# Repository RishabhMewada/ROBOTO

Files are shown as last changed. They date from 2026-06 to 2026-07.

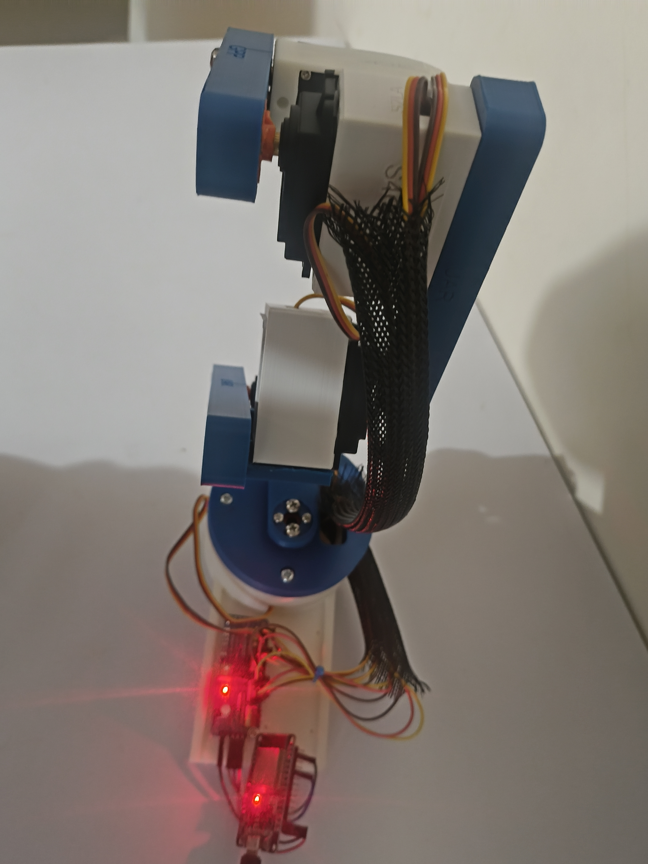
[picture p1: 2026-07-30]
Photos/IMG_20260730_174943996.jpg

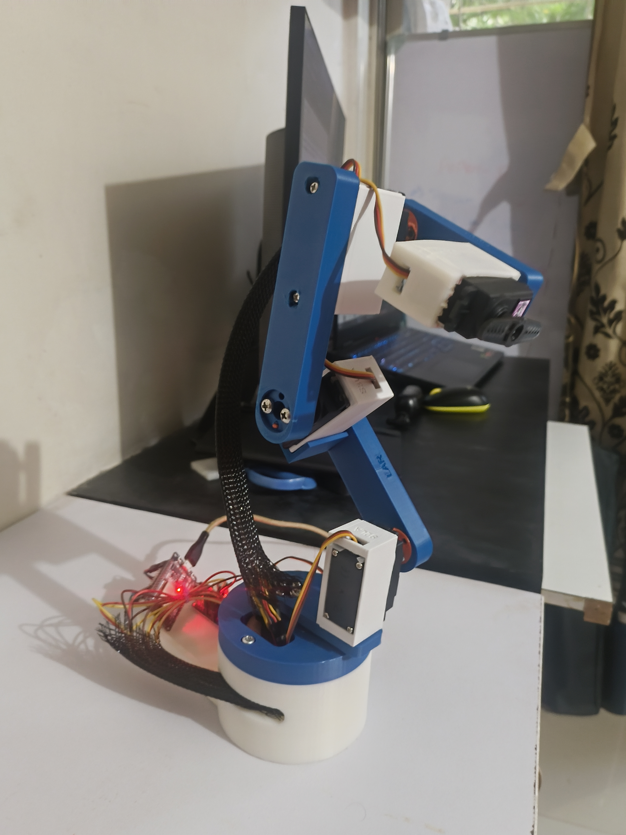
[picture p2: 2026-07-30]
Photos/IMG_20260730_175032654.jpg

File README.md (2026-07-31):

# ROBOTO

RB-1 (2)

>  An 6 degree of freedom (dof) robot driven by Waveshare WP5320 servo and an esp32 and
  servo driver the robot is controlled from a glove consisting of an esp32 & BNO055 and a
  battery pack

demo


## Table of Contents
- [Overview](#overview)
- [Hardware](#Hardware-&-Wiring-Diagram)
- [Software Architecture](#software-architecture)

## Overview
>'The why?'
 
**The sole purpose of this project is to help people build stuff and make them learn about robotics in comparatively affordable price and tinker around, in a much easier way to build and learn** and to be honest i also wanted to learn about robotics and improve my skills and build stuff which is hard to build !!

>The what?

**The project was build with one thing in mind, make it easy to connect and build (Like lego's !) , the project works on an ESP32 , and a PCA9685 servo driver to control the servo's and the servos's which are used in this project is Waveshare WP5320 *(it's MG996R servo in the project as it has similar diemensions to the WP5320 as i was not able to find the STEP file for it)* and BNO055 IMU to control the robot via hand gestures and a battery pack to power the glove side**

> The how?

**The project was Inspired from the S101 robot Repository and is built in fusion 360 with a minimilist Design Philosophy with a yet strong  build enough to handle its own weight and the objects it picks up without any bottleneck between the servo and it's built quality , and the entire robotic arm is build from ABS 3D printing material for a strong build with also some PLA in some parts of the robotic arm**

<p align="center">
ROBOTO-PARTS_2026-May-29_05-07-04PM-000_CustomizedView9396335264
</p>

## Hardware & Wiring Diagram

**Use the Wiring diagram as the Pin map for connecting everything and use the link above the diagram to get the exact pins!**

>Hardware (Robotic Arm)

1. ESP32 
2. PCA9685 Servo driver
3. Waveshare WP5320 Servo 180 Degree

>Wiring Schematic (Robotic Arm)

 [Click here to view the Schematic!](https://app.cirkitdesigner.com/project/19c6ec55-5556-4408-a9a6-c3da8fffa251)
 
RB-1 (3)

----------------------------------------------------------------------------------------------------------------------------------------------------------------------------------------------------------------------

>*Hardware (Glove)*

-Battery pack
1. 18650 Battery
2. TP4056 battery charger
3. MT608 boost converter
4. rocker switch
  
-Motion capture module
1. ESP32
2. BNO055 IMU 9-DOF
3. Flex Sensor
   
>Wiring Schematic (Glove)

 [Click here to view the Schematic!](https://app.cirkitdesigner.com/project/269f68dc-bc2f-4ff6-8df4-b6a70eb212e9)

RB-1

-----------------------------------------------------------------------------------------------------------------------------------------------------------------------------------------------------------------------------

### Bill of Materials

> Total project cost: **~$173.31 USD**

## Electronics

| # | Component | Purpose | Qty | Cost (USD) | Distributor |
|---|---|---|:---:|:---:|---|
| 1 | [ESP32 WROOM-32](https://robu.in/product/esp-wroom-32-wifi-bluetooth-networking-smart-component-development-board/) | Main control unit (glove + arm) | 2 | $8.70 | Robu.in |
| 2 | [BNO055 IMU](https://robu.in/product/df-robot-febno055-intelligent-9-axis-sensor-rmion-bno055-intelligent-9-axis-sensor-breakout/) | 9-axis IMU for arm motion tracking | 1 | $19.87 | Robu.in |
| 3 | [PCA9685](https://robocraze.com/products/pca9685-16-channel-servo-motor-driversoldered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) | 16-channel 12-bit servo driver | 1 | $2.40 | Robocraze.com |
| 4 | [WP5320 Servo](https://hubtronics.in/wp5320) | Arm joints + gripper (×6) | 6 | $82.30 | Hubtronics.in |
| 5 | [Flex Sensor 2.2"](https://robocraze.com/products/flex-sensor-2-2?variant=40192405504153&country=IN&currency=INR) | Gripper trigger on glove | 1 | $2.03 | Robocraze.com |

## Power System

| # | Component | Purpose | Qty | Cost (USD) | Distributor |
|---|---|---|:---:|:---:|---|
| 6 | [Samsung 18650 Li-Ion Battery](https://robu.in/product/samsung-18650-30q-li-ion-battery/) | Main power source for glove | 1 | $6.06 | Robu.in |
| 7 | [18650 Battery Holder](https://robu.in/product/1-x-18650-cell-box/) | Battery housing | 1 | $6.06 | Robu.in |
| 8 | [TP4056 Charger Module](https://robocraze.com/products/tp4056-battery-charger-c-type-module-with-protection-1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) | Li-Ion battery charger with protection | 1 | $0.15 | Robocraze.com |
| 9 | [MT3608 Boost Converter](https://robu.in/product/mt3608-2a-max-dc-dc-step-up-power-module-booster-power-module/) | Steps up battery voltage for ESP32 | 1 | $0.35 | Robocraze.com |
| 10 | [Rocker Switch](https://robu.in/product/6a-250v-ac-spst-on-off-rocker-switch/) | Power on/off | 1 | $0.17 | Robu.in |

## Mechanical & Build

| # | Component | Purpose | Qty | Cost (USD) | Distributor |
|---|---|---|:---:|:---:|---|
| 11 | [3D Printing Service](https://robu.in/product/3d-printing-service1/) | Arm structure parts | 16 | $34.96 | Robu.in |
| 12 | [Screws & Thread Inserts](https://onlyscrews.in/a/cart?cart-token=2tY5s2&link-token=10JKFq) | Assembly hardware | 1 | $4.10 | onlyscrews.in |

## Glove Assembly

| # | Component | Purpose | Qty | Cost (USD) | Distributor |
|---|---|---|:---:|:---:|---|
| 13 | [Fingerless Compression Glove](https://www.amazon.in/MOMISY-Copper-Infused-Fingerless-Compression-Tendonitis/dp/B09HV4BFLP) | Base for motion sensor pack | 1 | $5.02 | Amazon.in |
| 14 | [Velcro Straps](https://www.amazon.in/Glimzo-Velcro-Tape-Buckles-Management/dp/B0GX9J13YC) | Holds battery pack on hand | 1 | $0.72 | Amazon.in |
| 15 | [Jumper Wires (F-F 10cm)](https://robu.in/product/10cm-female-female-breadboard-jumper-dupont-2-54mm-1p-1p-cable-40-pcs/) | Module connections | 1 | $0.42 | Robu.in |

---

> **Note:** Prices are in USD and may vary by region. All Indian suppliers ship domestically.
> Servo power supply (5–6 V / 3 A BEC) is required separately for the arm and is not included above. 

## Software Architecture

- The system is split across two independent ESP32 microcontrollers communicating wirelessly in real time. The glove controller reads motion and finger data and then packages it into a compact struct, and broadcasts it over to the ESP-NOW at 50 Hz.
  
- The arm controller receives each packet and maps the orientation values to servo angles and it applies exponential smoothing, and drives six WP5320 servos through a PCA9685 PWM driver. No router, no Bluetooth pairing, no internet — the two boards talk directly peer-to-peer over 2.4 GHz with sub-5 ms latency
-----------------------------------------------------------------------------------------------------------------------------------------------------------------------------------------------------------------
## System Diagram

<p align="center">
 Group 1
</p>

-----------------------------------------------------------------------------------------------------------------------------------------------------------------------------------------------------------------

## Folder Structure

```robotic-glove-arm/
│
├── firmware/
│   ├── arm_esp32/
│   │   └── arm_esp32.ino        # Arm controller — ESP-NOW RX, PCA9685, servo mapping
│   ├── glove_esp32/
│   │   └── glove_esp32.ino      # Glove controller — BNO055, flex sensor, ESP-NOW TX
│   └── shared/
│       └── config.h             # GlovePacket struct, pin defines, shared constants
│
├── hardware/
│   ├── schematics/
│   │   ├── glove_wiring.png     # Exported wiring diagram
│   │   └── arm_wiring.png       # Exported wiring diagram
│   ├── cad/
│   │   └── arm_assembly.step    # Full CAD assembly of the robot
|   |   └── 3D print Files       #  3D models for 3D printing
│   └── BOM.csv                  # Part, qty, supplier, price, link
│
├── Images/
│   ├── banner.png               # README header image (1500×500 px)
|   └── robtic arm & glove       # CAD images of the robot and the glove
│
├── README.md
├── CHANGELOG.md
├── LICENSE
└── .gitignore
```

## Communication Protocol

- The two boards communicate exclusively over ESP-NOW — a connectionless, peer-to-peer Wi-Fi protocol built into the ESP32. No pairing process, no router required, and no TCP overhead. Once the arm's MAC address is registered as a peer on the glove, packets fire unidirectionally from glove to arm at 50 Hz with approximately 2–4 ms over-the-air latency.
Packet structure — GlovePacket (30 bytes)

```typedef struct __attribute__((packed)) {
    float    roll;        // degrees, offset-corrected  (-180 … +180)
    float    pitch;       // degrees, offset-corrected  (-90  … +90)
    float    yaw;         // degrees, offset-corrected  (0    … 360)
    float    quatW;       // quaternion W component
    float    quatX;       // quaternion X component
    float    quatY;       // quaternion Y component
    float    quatZ;       // quaternion Z component
    uint8_t  gripClose;   // 1 = close gripper, 0 = open
    uint8_t  calMode;     // 1 = calibration reset signal, 0 = normal
    int16_t  flexRaw;     // raw ADC value (0–4095) for diagnostics
} GlovePacket;            // total: 30 bytes
```
- Transmission
  
| Property | Value |
|---|---|
| Protocol | ESP-NOW (IEEE 802.11 vendor action frames) |
| Direction | Glove → Arm (unidirectional) |
| Frequency | 50 Hz (every 20 ms) |
| Packet size | 30 bytes |
| Latency | ~2–4 ms |
| Range | ~200 m open air, ~50 m indoors |
| Encryption | None (add `encrypt: true` in peer config to enable) |
| Timeout | 500 ms — arm returns to HOME if no packet received |

- Calibration packets — 

**when the user triggers calibration on the glove (BOOT button held 3 s), the glove captures its neutral orientation and flex thresholds, saves them to NVS, then sends one packet with calMode = 1. The arm receives this and moves to HOME position, resetting its own smoothing state. Normal calMode = 0 packets resume immediately after**

- Connection loss handling — 

**the arm tracks the timestamp of the last received packet. If 500 ms passes with no packet (glove powered off, out of range, or obstruction), all servo targets are set to HOME and the status LED blinks at 300 ms intervals until signal resumes**

------------------------------------------------------------------------------------------------------------------------------------------------------------------------------------------------------------------------
## Build it !!

### firmware

***for the step by step guide on how to install the firmware on the ESP32 and download the  Prerequisites required for the installation of the firmware on ESP32 and make it work please go to the guide pdf***
it would be lenghty to write it here
                                                                                 
```
Firmware-installation.pdf

``` 

## Wirring steps 

please follow the schematic diagram in the readme or visit the links here, and connect everything via female to female jumper wires or solder them wires onto the components , i recommend jumper wires it keeps the project components resuable!

1. [Click here to view the Schematic!](https://app.cirkitdesigner.com/project/19c6ec55-5556-4408-a9a6-c3da8fffa251) for the wiring of the robotic arm

2.  [Click here to view the Schematic!](https://app.cirkitdesigner.com/project/269f68dc-bc2f-4ff6-8df4-b6a70eb212e9) for the wiring of glove

please note that the wiring in glove will require the components to be soldered via wires, which should be connected by following the schematics for both the glove and the Arm

## Robotic Arm build & glove build

 **Robotic Arm build**
please refer to this video made from hack club lapse , this will help you make the robotic arm easily by viewing it properly and following the steps , currently its in video form after full completion there would be a dedicated guide pdf for everything as a go to solution

*Video Links*

Base : https://lapse.hackclub.com/timelapse/fq3q5Q8XxO8g

Arm : https://lapse.hackclub.com/timelapse/Uputkgdq-GtG

**alternatively there is also the video in  repository file**

```
 Video-guide/

```

**there are also photos in the** 

```
Photos/

```
**for your reference !**
 
## Usage & Demo
 Let me complete the build first !
 
## License
**MIT LICENSE**

## Zine
 <p align="center">
 RB-1
</p>

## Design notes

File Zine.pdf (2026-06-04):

# Not a

# normal Robot

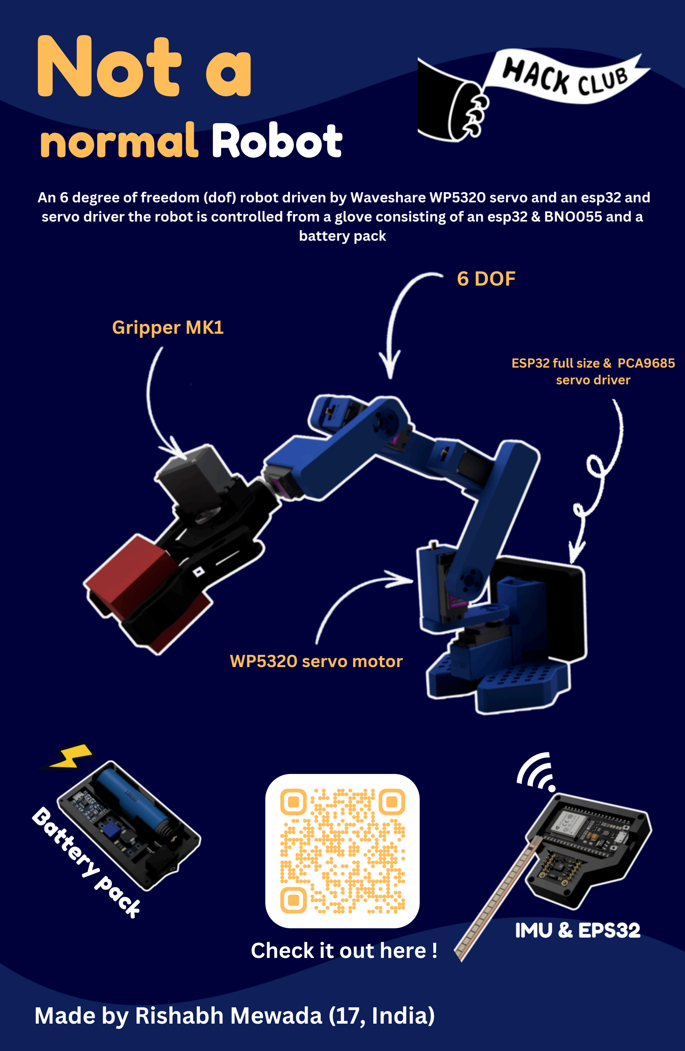
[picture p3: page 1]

An 6 degree of freedom (dof) robot driven by Waveshare WP5320 servo and an esp32 and servo driver the robot is controlled from a glove consisting of an esp32 & BNO055 and a battery pack

## Check it out here !

## Gripper MK1

## 6 DOF

### WP5320 servo motor

ESP32 full size & PCA9685
servo driver

# Battery pack

## IMU & EPS32

## Made by Rishabh Mewada (17, India)

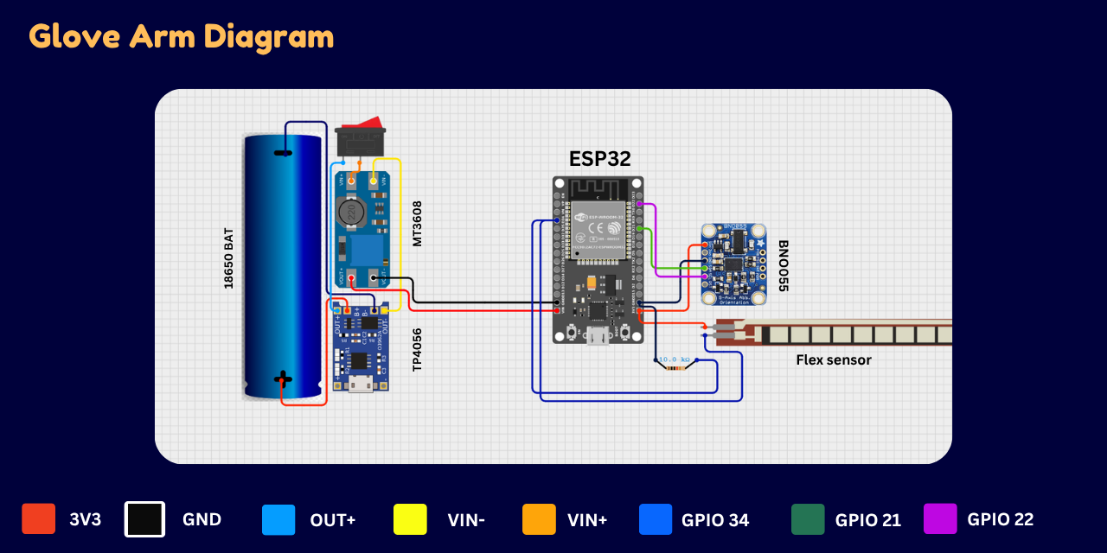
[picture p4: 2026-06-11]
Hardware/Schematics/Glove-Schematics.png

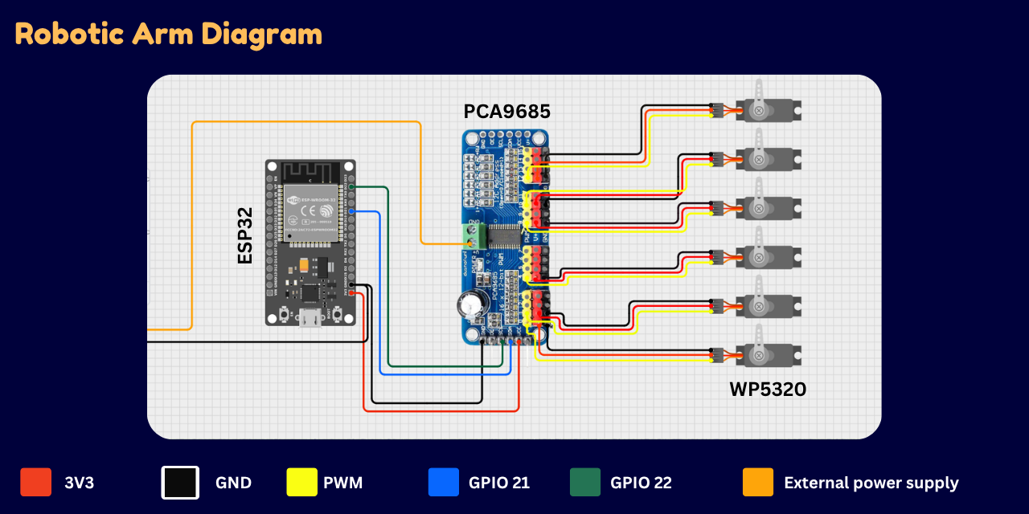
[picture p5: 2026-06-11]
Hardware/Schematics/RoboticArm-Schematics.png

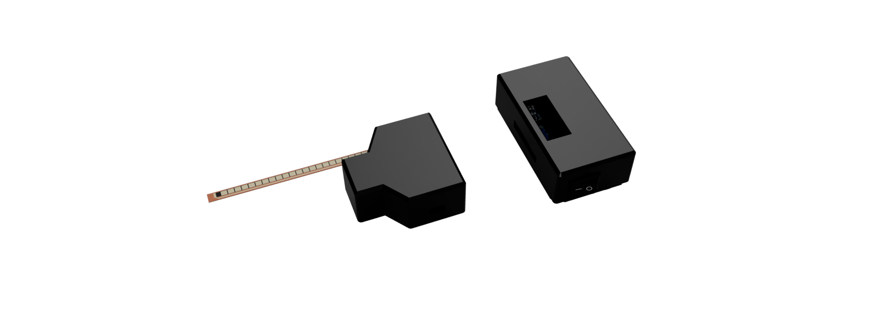
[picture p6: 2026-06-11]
Images/Glove-Images/glove-cad.PNG

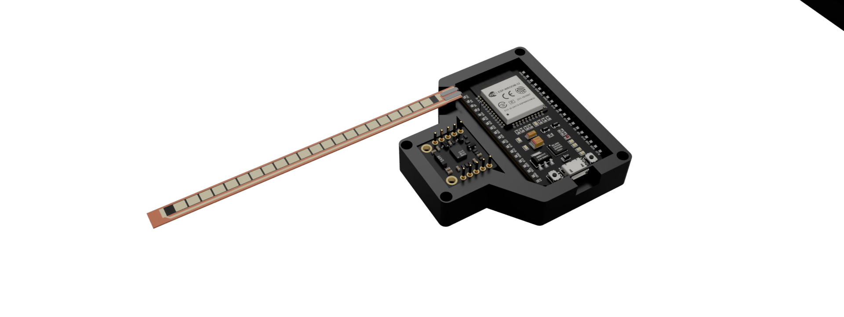
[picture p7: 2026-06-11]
Images/Glove-Images/ROBOTO-GLOVE-BNO055 & ESP32.png

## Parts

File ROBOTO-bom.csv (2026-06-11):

Name | Purpose | Quantity | Total Cost (USD) | Link | Distributor
screws and thread inserts | build | 1 | 4.10 | https://onlyscrews.in/a/cart?cart-token=2tY5s2&link-token=10JKFq | onlyscrews.in
3D Printing | build | 16 | 34.96 | https://robu.in/product/3d-printing-service1/ | Robu.in
Gloves | holding the motion sensor pack | 1 | 5.02 | https://www.amazon.in/MOMISY-Copper-Infused-Fingerless-Compression-Tendonitis/dp/B09HV4BFLP | Amazon.in
straps | for holding the battery pack on my hand | 1 | 0.72 | https://www.amazon.in/Glimzo-Velcro-Tape-Buckles-Management/dp/B0GX9J13YC | amazon.in
jumper wires | connection of modules | 1 | 0.42 | https://robu.in/product/10cm-female-female-breadboard-jumper-dupont-2-54mm-1p-1p-cable-40-pcs/ | Robu.in
flex sensor | gripper movement | 1 | 2.03 | https://robocraze.com/products/flex-sensor-2-2?variant=40192405504153&country=IN&currency=INR | Robocraze.com
BNO055 | IMU for robotic arm movement | 1 | 19.87 | https://robu.in/product/df-robot-febno055-intelligent-9-axis-sensor-rmion-bno055-intelligent-9-axis-sensor-breakout/ | Robu.in
switch | on/off | 1 | 0.17 | https://robu.in/product/6a-250v-ac-spst-on-off-rocker-switch/ | robu.in
MT3608 | Boost converter | 1 | 0.35 | https://robu.in/product/mt3608-2a-max-dc-dc-step-up-power-module-booster-power-module/ | robocraze.com
TP4056 | Battery charger | 1 | 0.15 | https://robocraze.com/products/tp4056-battery-charger-c-type-module-with-protection-1?variant=46170796261600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 | robocraze.com
18650 Battery holder | battery holder | 1 | 6.06 | https://robu.in/product/1-x-18650-cell-box/ | robu.in
18650 Li-Ion battery | battery | 1 | 6.06 | https://robu.in/product/samsung-18650-30q-li-ion-battery/ | robu.in
PCA9685 | Servo driver | 1 | 2.40 | https://robocraze.com/products/pca9685-16-channel-servo-motor-driversoldered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 | robocraze.com
WP5320 | SERVO | 6 | 82.30 | https://hubtronics.in/wp5320 | Hubtronics.in
ESP32 | Main control unit | 2 | 8.70 | https://robu.in/product/esp-wroom-32-wifi-bluetooth-networking-smart-component-development-board/ | Robu.in

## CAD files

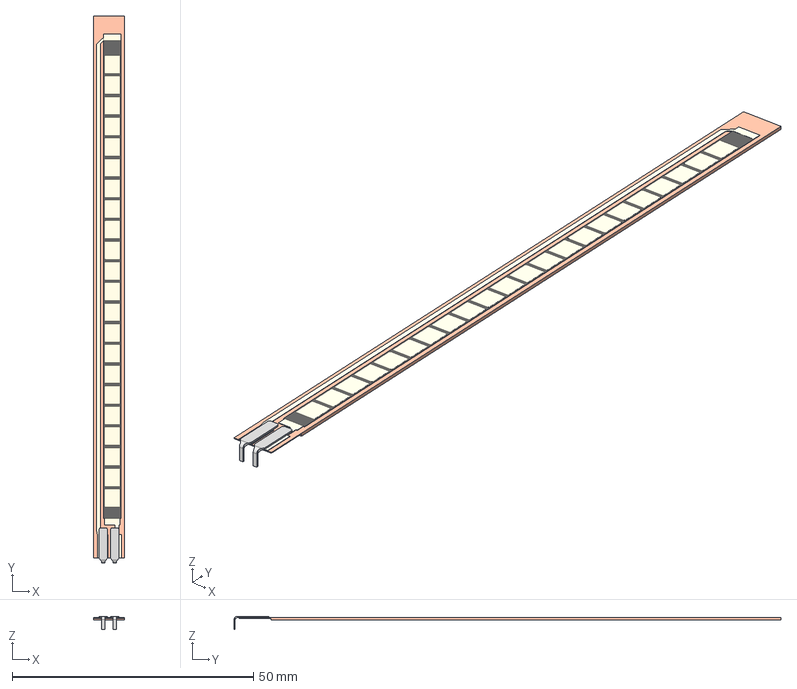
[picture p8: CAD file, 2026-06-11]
Component Library/FS-L-0095-103-ST - Assembly.stp
6.45 x 113.5 x 2.77 mm
FS-L-0095-103-ST - Base
FS-L-0095-103-ST - Top

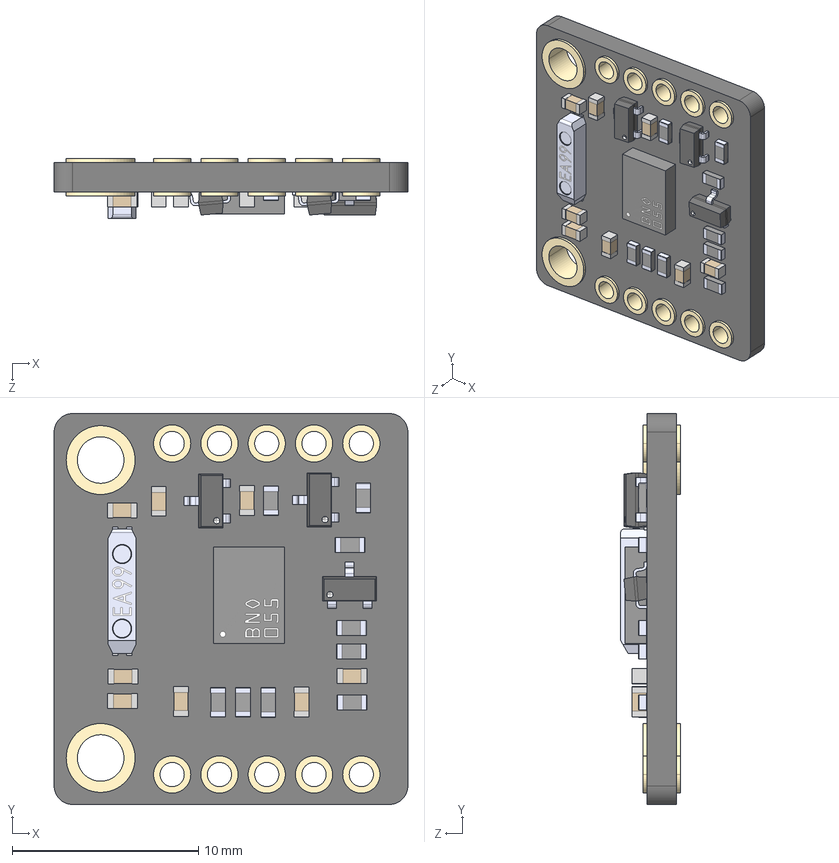
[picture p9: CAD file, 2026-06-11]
Component Library/bno055.STEP
19.0 x 21.0 x 3.20 mm
bno055_asm
User Library-LGA-28_5_2x3_8_0_5p.step
80836.stp x 9
User Library-SOT23-3.step x 3
capacitor_rnd_1500603b221k500.stp x 8
User Library-CSYTAL-MC146.step

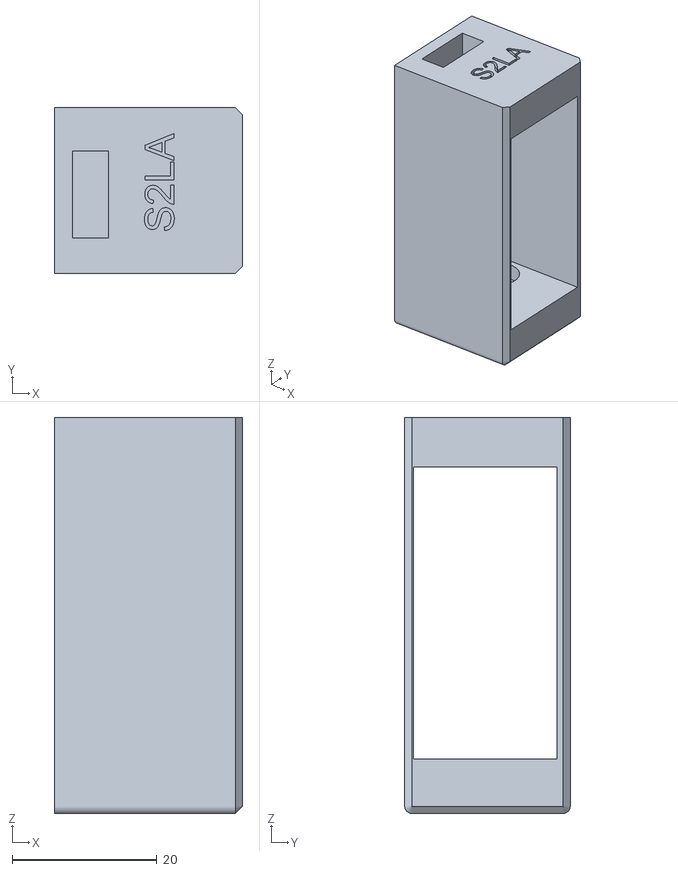
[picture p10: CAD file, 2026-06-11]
Hardware/3D Print/Arm-3D-Print/S2LA.stl
26.0 x 22.9 x 54.7

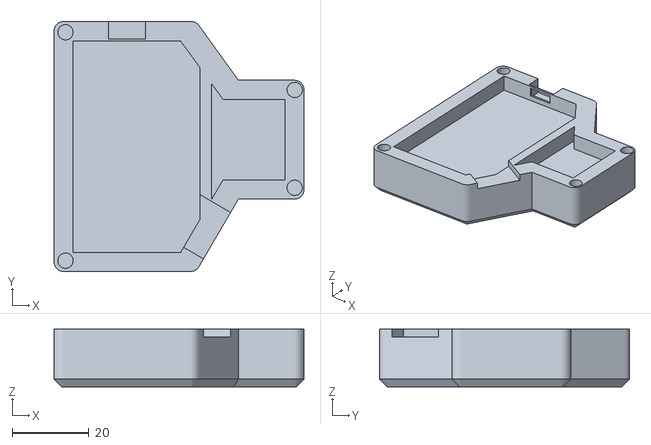
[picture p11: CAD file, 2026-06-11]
Hardware/3D Print/Glove-3D-print/GLOVE-SENSORBOX-LOWER.stl
65.1 x 65.1 x 15.0

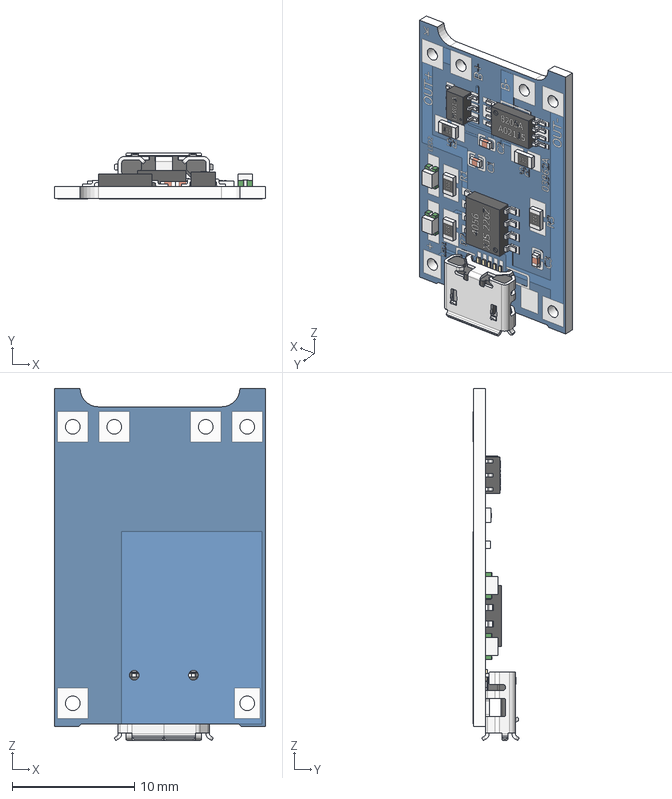
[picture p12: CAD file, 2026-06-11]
Component Library/TP4056.stp
17.3 x 3.75 x 28.9 mm
Board_TP4056
XJS_226Z
DW01-A
A02115
Capacitor_0603 x 3
Resistor (0603) x 3
Resistor (0603)_1
Resistor (0603)_2
Led x 2
Micro USB-B Female 5Pin SMD

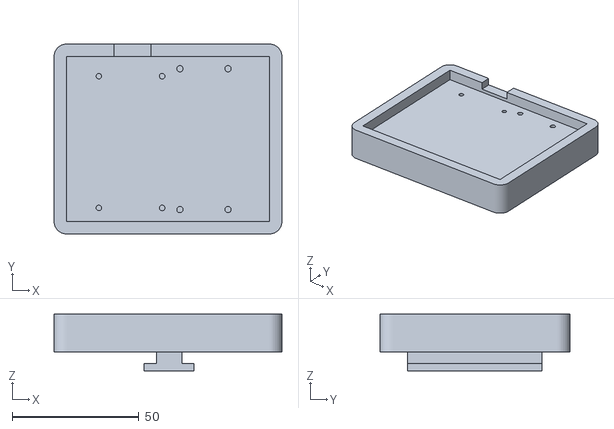
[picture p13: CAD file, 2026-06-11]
Hardware/3D Print/Arm-3D-Print/Mounting-plate.stl
90.0 x 75.0 x 22.4

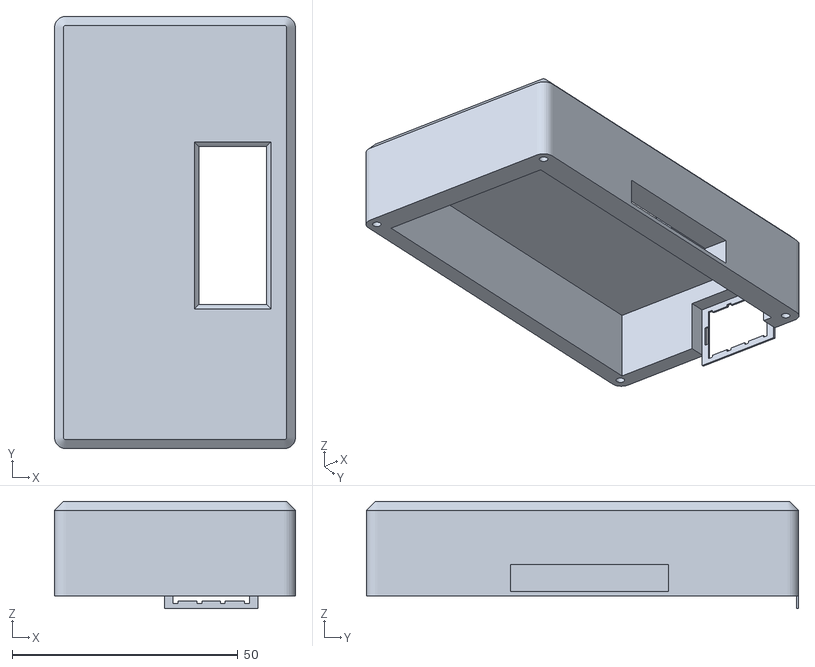
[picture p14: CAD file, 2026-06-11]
Hardware/3D Print/Glove-3D-print/GLOVE-BATTERYBOX-UPPERCASE.stl
53.4 x 95.9 x 23.8

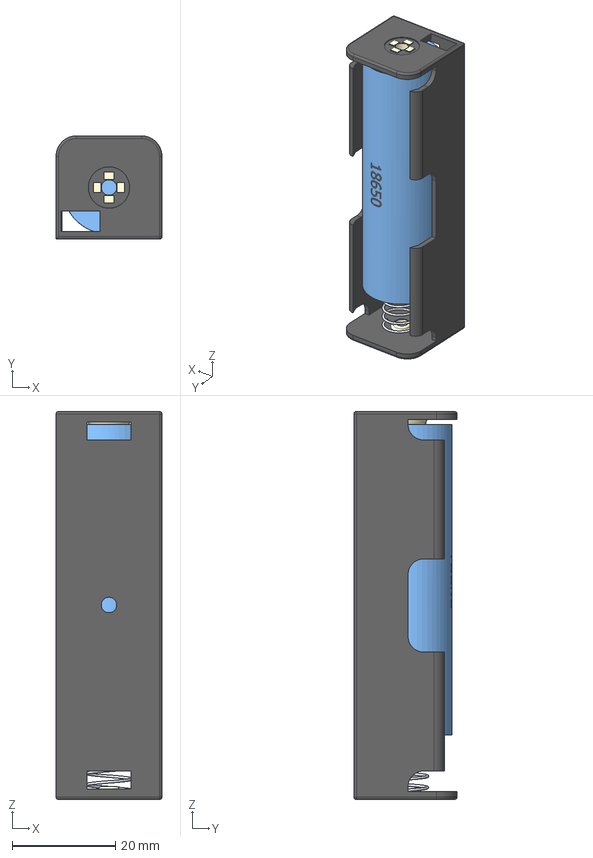
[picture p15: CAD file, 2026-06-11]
Component Library/Holder 18650 (1 cell)_blue.stp
20.5 x 20.0 x 75.0 mm

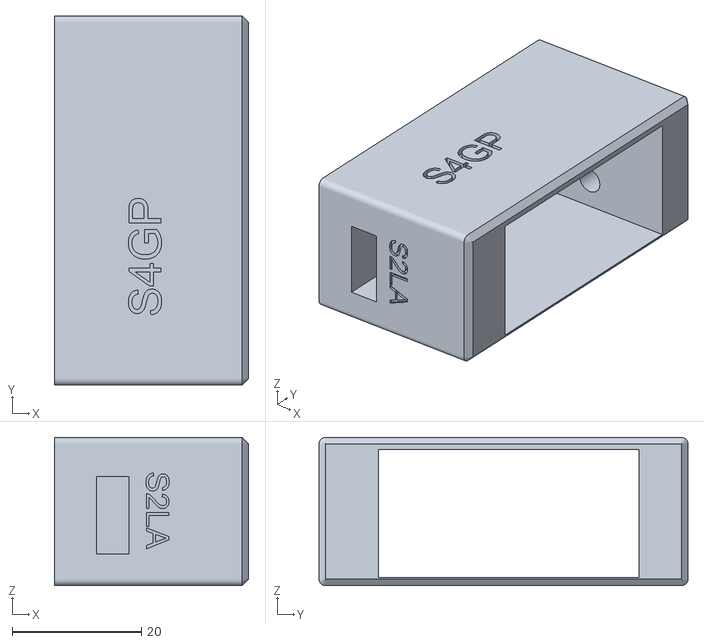
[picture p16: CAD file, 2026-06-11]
Hardware/3D Print/Arm-3D-Print/S4GP.stl
30.0 x 57.1 x 22.9

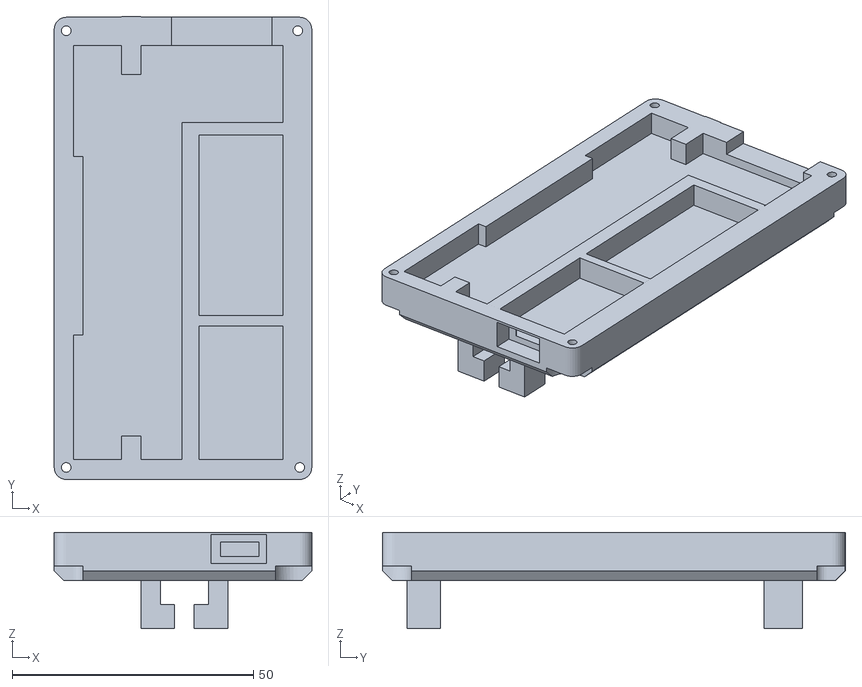
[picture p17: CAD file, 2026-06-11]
Hardware/3D Print/Glove-3D-print/GLOVE-BATTERYBOX-LOWERCASE.stl
53.4 x 96.0 x 20.0

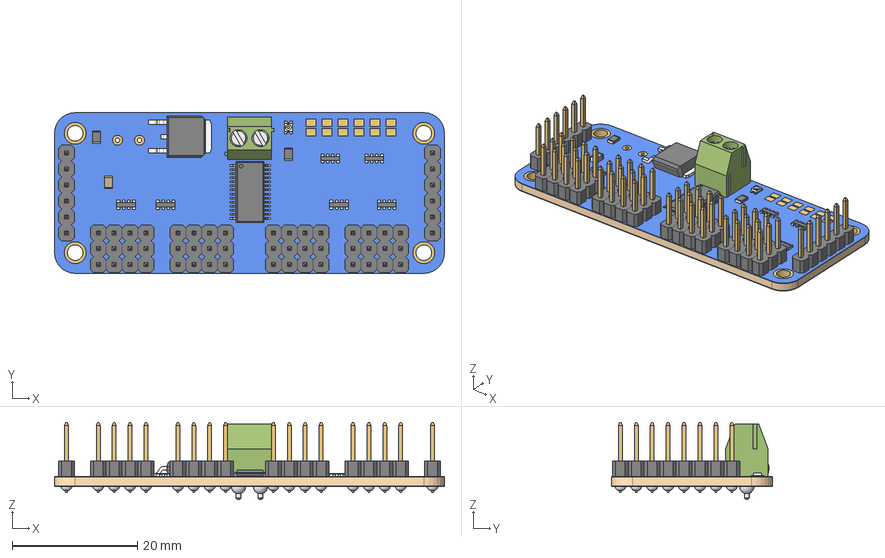
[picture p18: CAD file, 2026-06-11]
Component Library/PCA9685 16-Channel Servo Driver - Adafruit.step
62.2 x 25.7 x 12.4 mm

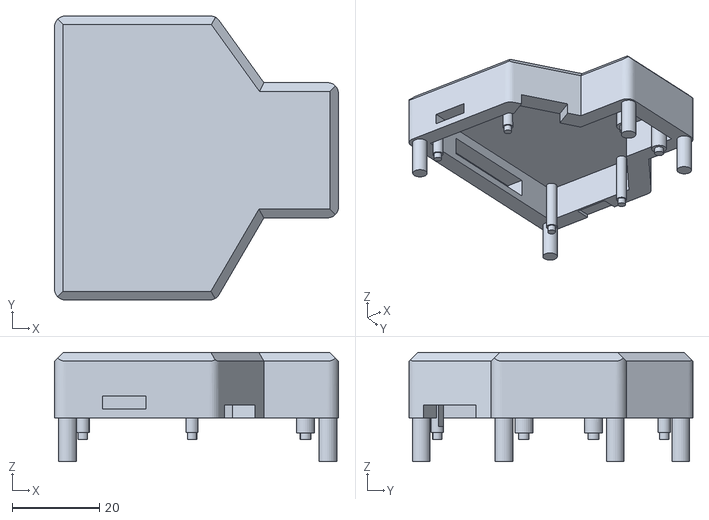
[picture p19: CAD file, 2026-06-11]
Hardware/3D Print/Glove-3D-print/GLOVE-SENSORBOX-UPPER.stl
65.1 x 65.1 x 25.0

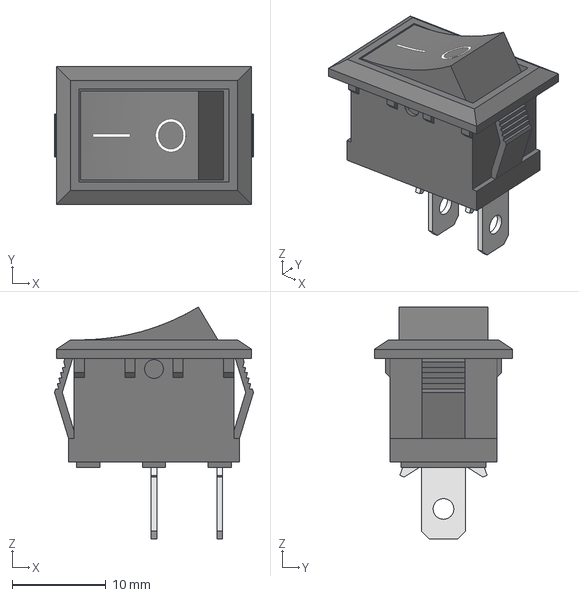
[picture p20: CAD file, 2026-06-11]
Component Library/Rocker Switch On Off.step
21.2 x 14.7 x 24.7 mm

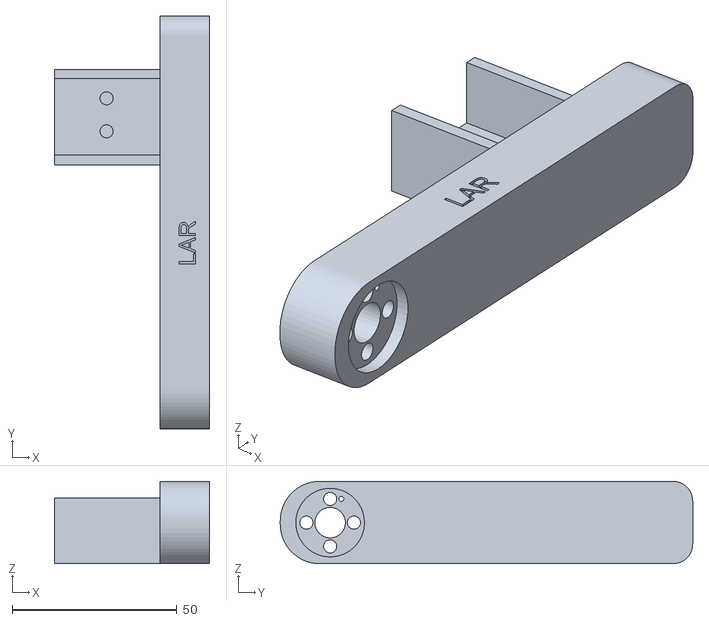
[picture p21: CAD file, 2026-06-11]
Hardware/3D Print/Arm-3D-Print/LAR.stl
47.0 x 125.1 x 25.0

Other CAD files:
Hardware/3D Print/Arm-3D-Print/S5GPP.stl
Component Library/MT3608 v3.step
Hardware/3D Print/Arm-3D-Print/GRIPPER-LID.stl
Hardware/3D Print/Arm-3D-Print/UAR.stl
Component Library/PCB_ESP32-38Pines.step
Component Library/SIP 100-5 v1.f3d
Component Library/mg996R_v2.step
Hardware/3D Print/Arm-3D-Print/ARM-1.stl
Hardware/3D Print/Arm-3D-Print/ARM-2.stl
Hardware/3D Print/Arm-3D-Print/BASE-V2.stl
Hardware/3D Print/Arm-3D-Print/BR.stl
Hardware/3D Print/Arm-3D-Print/GPP.stl
Hardware/3D Print/Arm-3D-Print/GRIPPER-BASE.stl
Hardware/3D Print/Arm-3D-Print/S1B.stl
Hardware/3D Print/Arm-3D-Print/S3UA.stl
Hardware/CAD/ROBOTO-GLOVE-CAD/ROBOTO-GLOVE-Render.f3z
Hardware/CAD/ROBOTO-GLOVE-CAD/ROBOTO-GLOVE.f3z

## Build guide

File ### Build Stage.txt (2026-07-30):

### Build Stage

**What changed in the build stage**

- A brand new base for 360 degree rotation for better wiring and cost effectiveness this decision reduced the overall cost of the base by 3$ , which helped alot with the 68$ budget  

- New refined components from the flaws that where identified during the assembly of everything 
- New diemensions and 3d print files for the servo holders due to the conflict between the servo wire output and the wall of the servo holder so extended it a little bit just right enough to fit it properly 

**What was made during this stage?**

- The main robotic arm was built with the new refined and improved components although the budget of 68$ limited the build to only the robotic arm and not the glove ( going to make it after this is approved with new flexible gripper design , and there is no gripper in the robotic arm as there was no budget to 3d print it, but with a new flexible gripper being devleoped and which will be integrated into the arm ( photos is attached at the end)

**what more is required ?**

- A gripper , all the glove components for a full project completion currently the robotic arm in this stage is experimently coded to run peer to peer with one esp 32 connected to the arm and one connected to the laptop which controls it via WASD keys and now it uses Inverse kinematics to make the robot move via sending the IK calculations to the robotic arm via the 2 esp 32's with the calculation done locally on the computer 

**what went wrong?!**

- wrong dimensions in the servo holders which was improved and added into the  robotic arm
- I DO NOT HAVE A POWER SUPPLY TO RUN THIS ARM :skull: neither a battery so a 2s battery will do the job 

so yeah it sitting here like a statue :skull:

***All the changes are made in the repository with the new files being present in Hardware/360-design  and build guide is added as a lapse video as it would be just to hard to guide by words and would be better to watch a video instead***

### Photos

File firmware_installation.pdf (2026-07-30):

## Firmware Installation Guide

Complete step-by-step instructions to install, configure, and flash both ESP32 boards for the ROBOTO glove-controlled robotic arm.

## Prerequisites

Hardware Required
- 2× ESP32 WROOM-32 development boards (Glove + Arm)
- 2× USB Micro-B cables (data cables — not charge-only)
- A Windows / macOS / Linux computer

## Step 1 — Install Arduino IDE

1. Go to https://www.arduino.cc/en/software
2. Download Arduino IDE 2.x (recommended) for your OS
3. Run the installer and follow the prompts
4. Launch Arduino IDE

## Step 2 — Install ESP32 Board Package

The Arduino IDE does not support ESP32 by default. You need to add it manually.
1. Open Arduino IDE
2. Go to File → Preferences
3. Find the field "Additional boards manager URLs"
4. Paste this URL into the field:

https://raw.githubusercontent.com/espressif/arduino-esp32/gh-pages/package_esp32_index.json

5. Click OK
6. Go to Tools → Board → Boards Manager
7. Search for esp32
8. Find "esp32 by Espressif Systems"
9. Click Install (version 2.0.x or later)
10.Wait for installation to complete (may take a few minutes)

## Step 3 — Install Required Libraries

Go to Sketch → Include Library → Manage Libraries and install each of the following:

Library Name | Author | How to Search
Adafruit BNO055 | Adafruit | Search BNO055
Adafruit Unified Sensor | Adafruit | Search Adafruit Unified Sensor
Adafruit PWM Servo Driver | Adafruit | Search PCA9685

Important: When installing Adafruit BNO055, Arduino IDE will ask: "Install missing dependencies?" — Click "Install All" This automatically installs Adafruit Unified Sensor as well.

## Step 4 — Download the Firmware

Clone or download the repository:

# Option A — Git clone

git clone https://github.com/YOUR_USERNAME/robotic-glove-arm.git

# Option B — Download ZIP

# Go to your GitHub repo → Code → Download ZIP → Extract

Your folder structure should look like this after extracting:

robotic-glove-arm/
├── firmware/
│ | ├── arm_esp32/
│ | │ | └── arm_esp32.ino
│ | ├── glove_esp32/
│ | │ | └── glove_esp32.ino
│ | └── shared/
│ | | └── config.h

## Step 5 — Configure Board Settings

Every time you open a sketch, set these board settings in Arduino IDE before flashing: Go to Tools menu and set:

Setting | Value
Board | ESP32 Dev Module
Upload Speed | 921600
CPU Frequency | 240MHz (WiFi/BT)

Setting | Value
Flash Frequency | 80MHz
Flash Mode | QIO
Flash Size | 4MB (32Mb)
Partition Scheme | Default 4MB with spiffs
Core Debug Level | None
PSRAM | Disabled

## Step 6 — Flash the ARM ESP32 First

The arm must be flashed first so you can get its MAC address for the glove firmware.

6.1 — Open the sketch
1. In Arduino IDE go to File → Open
2. Navigate to firmware/arm_esp32/arm_esp32.ino
3. Click Open

6.2 — Select the correct port
1. Plug the Arm ESP32 into your computer via USB
2. Go to Tools → Port
3. Select the port that appeared after plugging in:
- Windows: COM3, COM4, COM5 etc.
- macOS: /dev/cu.usbserial-XXXX
- Linux: /dev/ttyUSB0 or /dev/ttyACM0

Port not showing up? Install the CP2102 USB
driver: https://www.silabs.com/developers/usb-to-uart-bridge-vcp-drivers

6.3 — Upload the firmware
1. Click the Upload button (→ arrow) in Arduino IDE
2. Wait for Compiling sketch… then Uploading…
3. You will see:

Writing at 0x00010000... (100 %)
Leaving...
Hard resetting via RTS pin...
4. Upload is complete

6.4 — Get the Arm MAC address
1. Go to Tools → Serial Monitor
2. Set baud rate to 115200 (bottom right dropdown)
3. Press the EN/RST button on the ESP32
4. Look for this line in the output:

[NET] Arm MAC: AA:BB:CC:DD:EE:FF

5. Copy this MAC address — you will need it in the next step

## Step 7 — Set the ARM MAC in Glove Firmware

1. Open firmware/shared/config.h in any text editor
2. Find this line near the top of Section 5:
#define ARM_MAC | { 0xAA, 0xBB, 0xCC, 0xDD, 0xEE, 0xFF } | // ← REPLACE

THIS
3. Replace the placeholder bytes with your actual MAC address
Example: If your arm MAC is 3C:71:BF:4A:2D:08 change it to:

#define ARM_MAC { 0x3C, 0x71, 0xBF, 0x4A, 0x2D, 0x08 }

4. Save the file

## Step 8 — Flash the GLOVE ESP32

8.1 — Open the sketch
1. Go to File → Open
2. Navigate to firmware/glove_esp32/glove_esp32.ino
3. Click Open

8.2 — Select the correct port
1. Unplug the Arm ESP32
2. Plug in the Glove ESP32
3. Go to Tools → Port and select the new port

8.3 — Upload the firmware
1. Click the Upload button
2. Wait for upload to complete (same process as Step 6.3)

8.4 — Verify glove is running
1. Open Serial Monitor at 115200 baud
2. Press the EN/RST button on the Glove ESP32
3. You should see:

[GLOVE] Booting…
[OK] BNO055 ready
[CAL] Offsets loaded from NVS
[NET] Glove MAC: XX:XX:XX:XX:XX:XX
[OK] ESP-NOW ready → Arm MAC set
[GLOVE] Running — hold BOOT 3 s to calibrate

## Step 9 — Verify Full System Communication

1. Power on the Arm ESP32 (plug into USB or external supply)
2. Open Serial Monitor on the Arm board at 115200 baud
3. Power on the Glove ESP32
4. Move the glove — you should see live data on the arm Serial Monitor:
B:135 S:115 E:120 WP:135 WR:135 G:30 | RX R:0.0 P:0.0 Y:0.0
B:138 S:112 E:118 WP:140 WR:130 G:30 | RX R:5.2 P:-3.1 Y:2.8
5. The arm status LED (GPIO 2) should be solid ON when receiving packets
LED blinking? No signal is being received — check MAC address in config.h and re-flash glove firmware.

## Step 10 — Run Calibration

Glove calibration (always run first)
1. Hold the BOOT button on the Glove ESP32 for 3 seconds
2. Open Serial Monitor on the glove — follow the prompts:

========== CALIBRATION MODE ==========
Keep glove FLAT & STILL (neutral pose)… Starting in 5 s
3. Step through all three stages:
Stage | Action | Duration
Neutral pose | Hold hand flat and still | 5 s countdown then 1 s sample
Flex OPEN | Open hand fully and hold | 3 s
Flex CLOSE | Close hand into a fist and hold | 3 s

1. Offsets are saved automatically to NVS (survive power cycles)
2. LED blinks 6 times = calibration saved successfully

Arm trim calibration (run after glove calibration)
1. Hold the BOOT button on the Arm ESP32 for 3 seconds
2. Open Serial Monitor on the arm — you will see:

======== ARM CALIBRATION MODE ========
Commands:
t<ch> <deg> — set trim for channel (e.g. t0 -5.0) s<r|p|y> <f> — set scale (e.g. sr 0.8)
h | — send arm to HOME
q | — save & quit
3. Use the commands to fine-tune each servo:
Command | Example | Effect
t<ch> <deg> | t0 -5.0 | Shift base servo -5° from computed angle
t<ch> <deg> | t3 3.5 | Shift wrist pitch +3.5°
s<axis> <val> | sr 0.75 | Reduce roll sensitivity to 75%
s<axis> <val> | sy 1.2 | Increase yaw sensitivity to 120%
h | h | Move all servos to HOME position
q | q | Save all trims to NVS and exit
1. Type q when done — settings are saved permanently

## Troubleshooting

Problem | Likely Cause | Fix
Port not visible | Missing USB driver | Install CP2102 driver from Silicon Labs
BNO055 not found | Wrong wiring or 5V on VIN | Check SDA=21, SCL=22, VIN=3.3V only
Upload fails / timeout | Wrong port selected | Unplug, replug, re-select port
Upload fails — stuck at Connecting… | Boot mode issue | Hold BOOT button while clicking Upload, release when Uploading… appears
Arm LED blinking | No ESP-NOW signal | Check MAC address in config.h, re-flash glove
Servos not moving | Servo power rail issue | Check V+ screw terminal on

Problem | Likely Cause | Fix
| | PCA9685, verify external supply GND tied to ESP32 GND
Jittery movement | Power supply too weak | Use a dedicated 5V/3A BEC for servos
Gripper not triggering | Flex calibration wrong | Re-run glove calibration (BOOT 3 s)
Wrong servo direction | Map() range inverted | Swap minDeg and maxDeg in SERVO_CFG[] inside config.h

## Re-flashing After Changes

Whenever you edit config.h:
- Both boards must be re-flashed since config.h is shared
- Always flash Arm first, then Glove
- Re-run glove calibration after any re-flash to restore NVS offsets

## Serial Monitor Quick Reference

Board | Baud Rate | What you see
Glove | 115200 | Roll / Pitch / Yaw / Flex raw / Grip state
Arm | 115200 | 6 servo angles + received R/P/Y values

ROBOTO — 5-DOF Glove Controlled Robotic Arm

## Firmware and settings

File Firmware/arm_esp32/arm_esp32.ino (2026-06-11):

/*
 * ============================================================
 *  ROBOTIC ARM CONTROLLER — ESP32 WROOM 28-PIN
 *  Hardware : PCA9685 PWM Driver  +  WP5320 Servos (6 total)
 *             5 DOF arm  +  1 Gripper
 *  Input    : ESP-NOW packets from Glove ESP32
 * ============================================================
 *
 *  Wiring Summary
 *  ─────────────
 *  PCA9685  SDA  →  GPIO 21
 *  PCA9685  SCL  →  GPIO 22
 *  PCA9685  VIN  →  3.3 V (logic)
 *  PCA9685  V+   →  5–6 V  (servo power rail)
 *  PCA9685  GND  →  GND (common with ESP32 GND)
 *
 *  Servo Channel Map (PCA9685 channels 0-5)
 *  ─────────────────────────────────────────
 *  CH 0  →  Base    (yaw  / rotation)
 *  CH 1  →  Shoulder (pitch – lower)
 *  CH 2  →  Elbow   (pitch – upper)
 *  CH 3  →  Wrist Pitch
 *  CH 4  →  Wrist Roll
 *  CH 5  →  Gripper
 *
 *  Status LED  →  GPIO 2 (built-in, active HIGH)
 *  Cal button  →  GPIO 0 (BOOT, active LOW)
 *    Hold 3 s to enter arm-side calibration trim.
 * ============================================================
 */

#include <Arduino.h>
#include <Wire.h>
#include <WiFi.h>
#include <esp_now.h>
#include <Adafruit_PWMServoDriver.h>
#include <Preferences.h>

// ── PCA9685 ───────────────────────────────────────────────────
Adafruit_PWMServoDriver pca = Adafruit_PWMServoDriver(0x40, Wire);

// ── WP5320 Servo PWM Range ────────────────────────────────────
//  WP5320 is a standard 270° digital servo
//  Pulse width:  500 µs → 2500 µs  (adjust if your unit differs)
//  At 50 Hz the PCA9685 counts run 0-4095 (20 ms period)
//    count = (pulse_us / 20000) * 4096
#define SERVO_FREQ       50
#define PULSE_MIN_US     500
#define PULSE_MAX_US     2500
#define SERVO_COUNT      6

// ── Servo Channels ────────────────────────────────────────────
#define CH_BASE          0
#define CH_SHOULDER      1
#define CH_ELBOW         2
#define CH_WRIST_PITCH   3
#define CH_WRIST_ROLL    4
#define CH_GRIPPER       5

// ── Servo mechanical limits (degrees) ────────────────────────
//    Adjust per your physical setup to avoid binding!
struct ServoLimits {
    float minDeg;
    float maxDeg;
    float centerDeg;    // neutral / home position
} limits[SERVO_COUNT] = {
    {  0.0f, 270.0f, 135.0f },  // CH0 Base
    { 30.0f, 200.0f, 115.0f },  // CH1 Shoulder
    { 20.0f, 220.0f, 120.0f },  // CH2 Elbow
    { 30.0f, 240.0f, 135.0f },  // CH3 Wrist Pitch
    {  0.0f, 270.0f, 135.0f },  // CH4 Wrist Roll
    { 30.0f, 150.0f,  30.0f },  // CH5 Gripper  (30=open 150=close)
};

// ── Glove Data Packet (must match glove side exactly) ─────────
typedef struct __attribute__((packed)) {
    float roll;
    float pitch;
    float yaw;
    float quatW;
    float quatX;
    float quatY;
    float quatZ;
    uint8_t gripClose;
    uint8_t calMode;
    int16_t flexRaw;
} GlovePacket;

// ── Runtime servo targets & current positions ─────────────────
float targetDeg[SERVO_COUNT];
float currentDeg[SERVO_COUNT];

// ── Smoothing factor (0.0 = no movement, 1.0 = instant) ───────
//    Lower = smoother & slower.  0.12–0.18 feels natural.
const float ALPHA = 0.15f;

// ── Calibration trim offsets (arm side, stored in NVS) ────────
struct ArmCalib {
    float trimDeg[SERVO_COUNT];     // added to computed angle
    float rollScale;                // glove roll  → servo deg multiplier
    float pitchScale;
    float yawScale;
} armCal = {
    {0,0,0,0,0,0},
    1.0f, 1.0f, 1.0f
};

// ── Gripper FSM ───────────────────────────────────────────────
bool  lastGripClose   = false;
float gripTargetDeg   = 30.0f;     // open

// ── Comms State ───────────────────────────────────────────────
volatile bool   newPacket       = false;
GlovePacket     rxPkt;
unsigned long   lastRxMs        = 0;
const uint32_t  TIMEOUT_MS      = 500;  // go to safe-hold if no data

// ── Calibration ───────────────────────────────────────────────
bool  calPending        = false;
unsigned long calBtnPressMs = 0;
Preferences prefs;

// ── Status LED ────────────────────────────────────────────────
#define PIN_LED  2
#define PIN_CAL  0

// ─── Helpers ──────────────────────────────────────────────────

// Convert degrees to PCA9685 tick count
uint16_t degToTick(float deg, int ch) {
    // clamp
    deg = constrain(deg, limits[ch].minDeg, limits[ch].maxDeg);
    // map deg (0-270) to pulse width
    float pulseUs = map(deg * 100, 0, 27000,
                        PULSE_MIN_US * 100, PULSE_MAX_US * 100) / 100.0f;
    return (uint16_t)((pulseUs / 20000.0f) * 4096.0f);
}

void writeServo(int ch, float deg) {
    uint16_t tick = degToTick(deg + armCal.trimDeg[ch], ch);
    pca.setPWM(ch, 0, tick);
}

// Move all servos to home position
void goHome() {
    for (int i = 0; i < SERVO_COUNT; i++) {
        targetDeg[i]  = limits[i].centerDeg;
        currentDeg[i] = limits[i].centerDeg;
        writeServo(i, currentDeg[i]);
    }
    Serial.println("[ARM] Moved to HOME position");
}

// Load calibration from NVS
void loadArmCal() {
    prefs.begin("arm_cal", true);
    for (int i = 0; i < SERVO_COUNT; i++) {
        char key[16];
        snprintf(key, sizeof(key), "trim%d", i);
        armCal.trimDeg[i] = prefs.getFloat(key, 0.0f);
    }
    armCal.rollScale  = prefs.getFloat("rScale", 1.0f);
    armCal.pitchScale = prefs.getFloat("pScale", 1.0f);
    armCal.yawScale   = prefs.getFloat("yScale", 1.0f);
    prefs.end();
    Serial.println("[CAL] Arm calibration loaded");
}

void saveArmCal() {
    prefs.begin("arm_cal", false);
    for (int i = 0; i < SERVO_COUNT; i++) {
        char key[16];
        snprintf(key, sizeof(key), "trim%d", i);
        prefs.putFloat(key, armCal.trimDeg[i]);
    }
    prefs.putFloat("rScale", armCal.rollScale);
    prefs.putFloat("pScale", armCal.pitchScale);
    prefs.putFloat("yScale", armCal.yawScale);
    prefs.end();
    Serial.println("[CAL] Arm calibration saved");
}

// ── Interactive arm calibration via Serial ────────────────────
void runArmCalibration() {
    Serial.println("\n======== ARM CALIBRATION MODE ========");
    Serial.println("Commands:");
    Serial.println("  t<ch> <deg>  — set trim for channel (e.g. t0 -5.0)");
    Serial.println("  s<r|p|y> <f> — set scale (e.g. sr 0.8)");
    Serial.println("  h            — send arm to HOME");
    Serial.println("  q            — save & quit");
    Serial.println("======================================");

    // Sweep each servo to show user the current range
    Serial.println("Sweeping all servos to HOME…");
    goHome();
    delay(1000);

    while (true) {
        if (Serial.available()) {
            String cmd = Serial.readStringUntil('\n');
            cmd.trim();
            if (cmd.length() == 0) continue;

            char type = cmd.charAt(0);

            if (type == 'q') {
                saveArmCal();
                Serial.println("[CAL] Saved. Exiting calibration.");
                break;
            }
            else if (type == 'h') {
                goHome();
            }
            else if (type == 't') {
                int ch  = cmd.charAt(1) - '0';
                float v = cmd.substring(3).toFloat();
                if (ch >= 0 && ch < SERVO_COUNT) {
                    armCal.trimDeg[ch] = v;
                    writeServo(ch, limits[ch].centerDeg);
                    Serial.printf("  CH%d trim = %.2f°\n", ch, v);
                }
            }
            else if (type == 's') {
                char axis = cmd.charAt(1);
                float v   = cmd.substring(3).toFloat();
                if      (axis == 'r') { armCal.rollScale  = v; Serial.printf("  Roll scale  = %.3f\n", v); }
                else if (axis == 'p') { armCal.pitchScale = v; Serial.printf("  Pitch scale = %.3f\n", v); }
                else if (axis == 'y') { armCal.yawScale   = v; Serial.printf("  Yaw scale   = %.3f\n", v); }
            }
        }
        delay(10);
    }

    // Confirmation blinks
    for (int i = 0; i < 6; i++) {
        digitalWrite(PIN_LED, HIGH); delay(120);
        digitalWrite(PIN_LED, LOW);  delay(120);
    }
}

// ── ESP-NOW receive callback ───────────────────────────────────
void onDataRecv(const esp_now_recv_info_t *info, const uint8_t *data, int len) {
    if (len == sizeof(GlovePacket)) {
        memcpy((void*)&rxPkt, data, sizeof(GlovePacket));
        newPacket = true;
        lastRxMs  = millis();
    }
}

// ─────────────────────────────────────────────────────────────
void setup() {
    Serial.begin(115200);
    Serial.println("\n[ARM] Booting robotic arm controller…");

    pinMode(PIN_LED, OUTPUT);
    pinMode(PIN_CAL, INPUT_PULLUP);
    digitalWrite(PIN_LED, LOW);

    // I2C + PCA9685
    Wire.begin(21, 22);
    pca.begin();
    pca.setOscillatorFrequency(27000000);  // trim for accuracy
    pca.setPWMFreq(SERVO_FREQ);
    Serial.println("[OK] PCA9685 ready at 50 Hz");

    // Load arm calibration
    loadArmCal();

    // Init current positions at home
    for (int i = 0; i < SERVO_COUNT; i++) {
        currentDeg[i] = limits[i].centerDeg;
        targetDeg[i]  = limits[i].centerDeg;
    }
    goHome();
    delay(500);

    // Wi-Fi STA for ESP-NOW
    WiFi.mode(WIFI_STA);
    WiFi.disconnect();
    Serial.printf("[NET] Arm MAC: %s\n", WiFi.macAddress().c_str());
    Serial.println("  ↑ Copy this MAC into glove_esp32.ino → armMac[]");

    // ESP-NOW init
    if (esp_now_init() != ESP_OK) {
        Serial.println("[ERR] ESP-NOW init failed");
        while (true) delay(1000);
    }
    esp_now_register_recv_cb(onDataRecv);
    Serial.println("[OK] ESP-NOW listening for glove packets");
    Serial.println("[ARM] Ready — hold BOOT 3 s for calibration\n");
}

// ─────────────────────────────────────────────────────────────
void loop() {
    unsigned long now = millis();

    // ── Calibration button ────────────────────────────────────
    if (digitalRead(PIN_CAL) == LOW) {
        if (calBtnPressMs == 0) calBtnPressMs = now;
        if (now - calBtnPressMs > 3000 && !calPending) {
            calPending = true;
            runArmCalibration();
            calPending    = false;
            calBtnPressMs = 0;
        }
    } else {
        calBtnPressMs = 0;
    }

    // ── Connection timeout → safe hold ────────────────────────
    if (now - lastRxMs > TIMEOUT_MS && lastRxMs != 0) {
        // Hold current position — just keep smoothing toward home slowly
        for (int i = 0; i < SERVO_COUNT; i++)
            targetDeg[i] = limits[i].centerDeg;
        digitalWrite(PIN_LED, (now / 300) % 2);  // blink = no signal
    } else {
        digitalWrite(PIN_LED, HIGH);
    }

    // ── Process new packet ────────────────────────────────────
    if (newPacket) {
        newPacket = false;

        // If glove triggered calibration reset
        if (rxPkt.calMode) {
            Serial.println("[ARM] Cal-reset signal received from glove → going HOME");
            goHome();
        } else {
            /*
             * MAPPING STRATEGY
             * ─────────────────
             *  Glove orientation ranges are roughly:
             *    Roll   -90 … +90  (wrist lean)
             *    Pitch  -60 … +60  (tilt fwd/back)
             *    Yaw      0 … 360  (rotation)
             *
             *  We remap these to servo angles.
             *  Tweak the map() calls to taste or adjust via scale in cal.
             */

            // CH0 Base — driven by Yaw
            float baseTarget = map(rxPkt.yaw * 10,
                                   -1800, 1800,
                                   limits[CH_BASE].minDeg * 10,
                                   limits[CH_BASE].maxDeg * 10) / 10.0f;
            targetDeg[CH_BASE] = constrain(baseTarget * armCal.yawScale,
                                           limits[CH_BASE].minDeg,
                                           limits[CH_BASE].maxDeg);

            // CH1 Shoulder — driven by Pitch (tilt forward = shoulder down)
            float shoulderTarget = map(rxPkt.pitch * 10,
                                       -600, 600,
                                       limits[CH_SHOULDER].maxDeg * 10,
                                       limits[CH_SHOULDER].minDeg * 10) / 10.0f;
            targetDeg[CH_SHOULDER] = constrain(shoulderTarget * armCal.pitchScale,
                                               limits[CH_SHOULDER].minDeg,
                                               limits[CH_SHOULDER].maxDeg);

            // CH2 Elbow — driven by Pitch (upper half range)
            float elbowTarget = map(rxPkt.pitch * 10,
                                    -600, 600,
                                    limits[CH_ELBOW].minDeg * 10,
                                    limits[CH_ELBOW].maxDeg * 10) / 10.0f;
            targetDeg[CH_ELBOW] = constrain(elbowTarget * armCal.pitchScale,
                                            limits[CH_ELBOW].minDeg,
                                            limits[CH_ELBOW].maxDeg);

            // CH3 Wrist Pitch — driven by Roll
            float wristPTarget = map(rxPkt.roll * 10,
                                     -900, 900,
                                     limits[CH_WRIST_PITCH].minDeg * 10,
                                     limits[CH_WRIST_PITCH].maxDeg * 10) / 10.0f;
            targetDeg[CH_WRIST_PITCH] = constrain(wristPTarget * armCal.rollScale,
                                                   limits[CH_WRIST_PITCH].minDeg,
                                                   limits[CH_WRIST_PITCH].maxDeg);

            // CH4 Wrist Roll — also driven by Roll (inverted feel)
            float wristRTarget = map(rxPkt.roll * 10,
                                     -900, 900,
                                     limits[CH_WRIST_ROLL].maxDeg * 10,
                                     limits[CH_WRIST_ROLL].minDeg * 10) / 10.0f;
            targetDeg[CH_WRIST_ROLL] = constrain(wristRTarget * armCal.rollScale,
                                                  limits[CH_WRIST_ROLL].minDeg,
                                                  limits[CH_WRIST_ROLL].maxDeg);

            // CH5 Gripper — binary from flex sensor
            if (rxPkt.gripClose && !lastGripClose) {
                gripTargetDeg = limits[CH_GRIPPER].maxDeg;  // CLOSE
                Serial.println("[GRIP] Close");
            } else if (!rxPkt.gripClose && lastGripClose) {
                gripTargetDeg = limits[CH_GRIPPER].minDeg;  // OPEN
                Serial.println("[GRIP] Open");
            }
            lastGripClose = rxPkt.gripClose;
            targetDeg[CH_GRIPPER] = gripTargetDeg;
        }
    }

    // ── Smooth interpolation (exponential filter) ─────────────
    for (int i = 0; i < SERVO_COUNT; i++) {
        currentDeg[i] = currentDeg[i] + ALPHA * (targetDeg[i] - currentDeg[i]);
        writeServo(i, currentDeg[i]);
    }

    // ── Debug output at ~5 Hz ──────────────────────────────────
    static unsigned long lastDbg = 0;
    if (now - lastDbg > 200) {
        lastDbg = now;
        Serial.printf("B:%.0f S:%.0f E:%.0f WP:%.0f WR:%.0f G:%.0f | RX R:%.1f P:%.1f Y:%.1f\n",
                       currentDeg[0], currentDeg[1], currentDeg[2],
                       currentDeg[3], currentDeg[4], currentDeg[5],
                       rxPkt.roll, rxPkt.pitch, rxPkt.yaw);
    }

    delay(10);  // ~100 Hz loop for smooth ALPHA filtering
}

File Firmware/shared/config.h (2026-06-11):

/*
 * ============================================================
 *  config.h  —  Shared configuration for ROBOTO
 *  Include this file in BOTH:
 *    → firmware/glove_esp32/glove_esp32.ino
 *    → firmware/arm_esp32/arm_esp32.ino
 * ============================================================
 *
 *  Verified against wiring diagrams:
 *    RB-1.png       — Glove Arm Diagram
 *    RB-1__3_.png   — Robotic Arm Diagram
 * ============================================================
 */

#pragma once

// ============================================================
//  SECTION 1 — GLOVE ESP32 PIN DEFINITIONS
//  (from Glove Arm Diagram — RB-1.png)
// ============================================================

// ── I²C Bus (BNO055) ─────────────────────────────────────────
#define GLOVE_PIN_SDA           21      // GPIO 21 → BNO055 SDA  (green wire)
#define GLOVE_PIN_SCL           22      // GPIO 22 → BNO055 SCL  (purple wire)

// ── Flex Sensor ───────────────────────────────────────────────
#define GLOVE_PIN_FLEX          34      // GPIO 34 → Flex sensor via 10kΩ divider
                                        // (blue wire — ADC1_CH6, input only)

// ── Power & Control ───────────────────────────────────────────
#define GLOVE_PIN_LED           2       // GPIO 2  → Built-in status LED
#define GLOVE_PIN_CAL_BTN       0       // GPIO 0  → BOOT button (calibration trigger)
                                        //           Hold 3 s to enter calibration

// ── Power Rail (reference only — not digitalWrite'd) ─────────
// 3V3  → BNO055 VIN                    (red wire)
// GND  → BNO055 GND, Flex GND, common  (black wire)
// VIN  → MT3608 VOUT                   (blue OUT+ wire from boost converter)
// MT3608 VIN+ → TP4056 OUT+            (yellow/orange wires)
// TP4056 B+/B- → 18650 battery         (red/black)
// Rocker switch → MT3608 VIN+ rail     (power on/off)


// ============================================================
//  SECTION 2 — ARM ESP32 PIN DEFINITIONS
//  (from Robotic Arm Diagram — RB-1__3_.png)
// ============================================================

// ── I²C Bus (PCA9685) ────────────────────────────────────────
#define ARM_PIN_SDA             21      // GPIO 21 → PCA9685 SDA  (blue wire)
#define ARM_PIN_SCL             22      // GPIO 22 → PCA9685 SCL  (green wire)

// ── Power & Control ───────────────────────────────────────────
#define ARM_PIN_LED             2       // GPIO 2  → Built-in status LED
#define ARM_PIN_CAL_BTN         0       // GPIO 0  → BOOT button (arm trim mode)

// ── Power Rail (reference only) ───────────────────────────────
// 3V3  → PCA9685 VCC  (logic power)    (red wire)
// GND  → PCA9685 GND + Servo GND       (black wire — common ground)
// External supply (+) → PCA9685 V+     (orange wire — servo power rail)
// External supply (-) → GND            (black wire — MUST share common GND)


// ============================================================
//  SECTION 3 — PCA9685 SERVO CHANNEL MAP
//  (from Robotic Arm Diagram — channels 0-5, top to bottom)
// ============================================================

#define SERVO_CH_BASE           0       // CH 0 — Base rotation    (driven by Yaw)
#define SERVO_CH_SHOULDER       1       // CH 1 — Shoulder         (driven by Pitch)
#define SERVO_CH_ELBOW          2       // CH 2 — Elbow            (driven by Pitch)
#define SERVO_CH_WRIST_PITCH    3       // CH 3 — Wrist Pitch      (driven by Roll)
#define SERVO_CH_WRIST_ROLL     4       // CH 4 — Wrist Roll       (driven by Roll)
#define SERVO_CH_GRIPPER        5       // CH 5 — Gripper          (driven by Flex)
#define SERVO_COUNT             6       // Total servo count

// ── WP5320 PWM Parameters ─────────────────────────────────────
#define SERVO_PWM_FREQ          50      // Hz  — standard servo frequency
#define SERVO_PULSE_MIN_US      500     // µs  — 0°   position pulse width
#define SERVO_PULSE_MAX_US      2500    // µs  — 270° position pulse width

// ── PCA9685 I²C Address ───────────────────────────────────────
#define PCA9685_I2C_ADDR        0x40    // Default address (all ADDR pins to GND)
#define PCA9685_OSC_FREQ        27000000UL  // 27 MHz — trimmed oscillator value

// ── BNO055 I²C Address ────────────────────────────────────────
#define BNO055_I2C_ADDR         0x28    // Default (ADR pin to GND)


// ============================================================
//  SECTION 4 — SERVO MECHANICAL LIMITS (degrees)
//  Adjust minDeg / maxDeg to match your physical build.
//  centerDeg = safe home / neutral position.
// ============================================================

struct ServoConfig {
    const char* name;
    float       minDeg;
    float       maxDeg;
    float       centerDeg;
};
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

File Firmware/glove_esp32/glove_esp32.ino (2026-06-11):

/*
 * ============================================================
 *  GLOVE CONTROLLER — ESP32 WROOM 28-PIN
 *  Hardware : BNO055 IMU  +  Flex Sensor (ADC)  +  ESP-NOW TX
 *  Target   : Robotic Arm ESP32 (peer MAC set below)
 * ============================================================
 *
 *  Wiring Summary
 *  ─────────────
 *  BNO055  SDA  →  GPIO 21
 *  BNO055  SCL  →  GPIO 22
 *  BNO055  VIN  →  3.3 V
 *  BNO055  GND  →  GND
 *
 *  Flex Sensor  →  GPIO 34 (ADC1_CH6)  via voltage divider
 *                  (10 kΩ from 3.3 V, sensor to GND)
 *
 *  Status LED   →  GPIO 2  (built-in LED, active HIGH)
 *
 *  Calibration button → GPIO 0 (BOOT button, active LOW)
 *    Hold 3 s to enter calibration mode.
 * ============================================================
 */

#include <Arduino.h>
#include <Wire.h>
#include <Adafruit_Sensor.h>
#include <Adafruit_BNO055.h>
#include <esp_now.h>
#include <WiFi.h>
#include <Preferences.h>

// ── Pin Definitions ──────────────────────────────────────────
#define PIN_FLEX        34      // ADC – flex sensor
#define PIN_LED         2       // Status LED
#define PIN_CAL_BTN     0       // BOOT button for calibration

// ── Flex Sensor Thresholds (raw ADC 0-4095) ──────────────────
#define FLEX_OPEN_RAW   1500    // finger straight  → override in cal
#define FLEX_CLOSE_RAW  2800    // finger bent      → override in cal
#define FLEX_HYST       80      // hysteresis to avoid chatter

// ── BNO055 ───────────────────────────────────────────────────
Adafruit_BNO055 bno = Adafruit_BNO055(55, 0x28, &Wire);

// ── Preferences (NVS) for persistent calibration ─────────────
Preferences prefs;

// ── ARM MAC ADDRESS ──────────────────────────────────────────
//  *** Replace with the actual MAC of your Arm ESP32 ***
uint8_t armMac[6] = { 0xAA, 0xBB, 0xCC, 0xDD, 0xEE, 0xFF };

// ── Data Packet (must match arm side exactly) ─────────────────
typedef struct __attribute__((packed)) {
    float roll;          // degrees  -180 … +180
    float pitch;         // degrees  -90  … +90
    float yaw;           // degrees  0    … 360
    float quatW;         // quaternion W
    float quatX;
    float quatY;
    float quatZ;
    uint8_t gripClose;   // 1 = close gripper
    uint8_t calMode;     // 1 = calibration packet
    int16_t flexRaw;     // raw ADC for arm-side display
} GlovePacket;

// ── Calibration offsets stored in NVS ────────────────────────
struct CalOffset {
    float rollOffset;
    float pitchOffset;
    float yawOffset;
    int   flexOpen;
    int   flexClose;
} calOff = {0.0f, 0.0f, 0.0f, FLEX_OPEN_RAW, FLEX_CLOSE_RAW};

// ── Runtime State ─────────────────────────────────────────────
GlovePacket pkt;
bool  gripState      = false;   // current gripper state (with hysteresis)
bool  calPending     = false;
unsigned long calBtnPressTime = 0;
unsigned long lastSendMs      = 0;
const uint16_t SEND_INTERVAL_MS = 20;  // 50 Hz

// ── ESP-NOW send callback ─────────────────────────────────────
void onDataSent(const uint8_t *mac, esp_now_send_status_t status) {
    // Blink LED on successful send
    if (status == ESP_NOW_SEND_SUCCESS) {
        digitalWrite(PIN_LED, HIGH);
        delayMicroseconds(500);
        digitalWrite(PIN_LED, LOW);
    }
}

// ── Load calibration from NVS ─────────────────────────────────
void loadCalibration() {
    prefs.begin("glove_cal", true);
    calOff.rollOffset  = prefs.getFloat("rollOff",  0.0f);
    calOff.pitchOffset = prefs.getFloat("pitchOff", 0.0f);
    calOff.yawOffset   = prefs.getFloat("yawOff",   0.0f);
    calOff.flexOpen    = prefs.getInt("flexOpen",   FLEX_OPEN_RAW);
    calOff.flexClose   = prefs.getInt("flexClose",  FLEX_CLOSE_RAW);
    prefs.end();
    Serial.println("[CAL] Offsets loaded from NVS");
    Serial.printf("  Roll=%.2f  Pitch=%.2f  Yaw=%.2f\n",
                  calOff.rollOffset, calOff.pitchOffset, calOff.yawOffset);
    Serial.printf("  FlexOpen=%d  FlexClose=%d\n",
                  calOff.flexOpen, calOff.flexClose);
}

// ── Save calibration to NVS ───────────────────────────────────
void saveCalibration() {
    prefs.begin("glove_cal", false);
    prefs.putFloat("rollOff",   calOff.rollOffset);
    prefs.putFloat("pitchOff",  calOff.pitchOffset);
    prefs.putFloat("yawOff",    calOff.yawOffset);
    prefs.putInt("flexOpen",    calOff.flexOpen);
    prefs.putInt("flexClose",   calOff.flexClose);
    prefs.end();
    Serial.println("[CAL] Offsets saved to NVS");
}

// ── Run interactive calibration via Serial ────────────────────
void runCalibration() {
    Serial.println("\n========== CALIBRATION MODE ==========");
    Serial.println("Keep glove FLAT & STILL (neutral pose)…");

    // Wait for BNO055 to settle
    for (int i = 5; i > 0; i--) {
        Serial.printf("  Starting in %d s\r", i);
        delay(1000);
    }
    Serial.println();

    // Sample neutral pose over 1 second (50 samples)
    float sumR = 0, sumP = 0, sumY = 0;
    for (int s = 0; s < 50; s++) {
        sensors_event_t ev;
        bno.getEvent(&ev);
        sumR += ev.orientation.z;   // BNO055 roll
        sumP += ev.orientation.y;   // pitch
        sumY += ev.orientation.x;   // yaw/heading
        delay(20);
    }
    calOff.rollOffset  = sumR / 50.0f;
    calOff.pitchOffset = sumP / 50.0f;
    calOff.yawOffset   = sumY / 50.0f;
    Serial.printf("[CAL] Neutral → Roll=%.2f  Pitch=%.2f  Yaw=%.2f\n",
                  calOff.rollOffset, calOff.pitchOffset, calOff.yawOffset);

    // Flex sensor open
    Serial.println("\n[CAL] OPEN your hand fully and hold…");
    delay(3000);
    long sumFlex = 0;
    for (int s = 0; s < 50; s++) { sumFlex += analogRead(PIN_FLEX); delay(20); }
    calOff.flexOpen = (int)(sumFlex / 50);
    Serial.printf("[CAL] Flex OPEN raw = %d\n", calOff.flexOpen);

    // Flex sensor closed
    Serial.println("[CAL] CLOSE your hand fully and hold…");
    delay(3000);
    sumFlex = 0;
    for (int s = 0; s < 50; s++) { sumFlex += analogRead(PIN_FLEX); delay(20); }
    calOff.flexClose = (int)(sumFlex / 50);
    Serial.printf("[CAL] Flex CLOSE raw = %d\n", calOff.flexClose);

    saveCalibration();

    // Send a calibration packet to arm so it can reset its own offsets
    memset(&pkt, 0, sizeof(pkt));
    pkt.calMode = 1;
    esp_now_send(armMac, (uint8_t*)&pkt, sizeof(pkt));
    delay(100);

    Serial.println("[CAL] Calibration complete! Resuming normal operation.");
    Serial.println("======================================\n");

    // Long LED blink to signal done
    for (int i = 0; i < 6; i++) {
        digitalWrite(PIN_LED, HIGH); delay(150);
        digitalWrite(PIN_LED, LOW);  delay(150);
    }
}
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

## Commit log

2026-06-09 Enhance README with project information and diagrams
    Expanded the README with project details, including overview, hardware, wiring, and software architecture.
2026-06-11 ADDITION OF STEP AND autodesk fusion files
    [ROBOTO-GLOVE-Render.f3z, ROBOTO-GLOVE.f3z]
2026-06-11 file error
    ADDITION OF STEP AND autodesk fusion files
    [ROBOTO-GLOVE-Render.f3z, ROBOTO-GLOVE.f3z]
2026-06-11 new files
    [ROBOTO-GLOVE-Render.f3z, ROBOTO-GLOVE.f3z]
2026-07-30 New 360 rotation design
    saves money
    [360-BASE.stl, 360-LID.stl, BR.stl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]
2026-07-30 Enhance README with robotic arm build instructions
    Updated the README with detailed instructions for building the robotic arm and included video links for guidance.
2026-07-30 Rename timelapse (1).mp4 to Arm
